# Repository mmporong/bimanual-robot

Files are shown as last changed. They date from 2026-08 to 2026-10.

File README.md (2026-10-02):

# HOLD THE FLOW · 이동형 양팔 물 서빙 로봇

웹에서 테이블의 물 주문을 받아 주방에서 물을 따르고, 컵을 상판에 싣고 이동해
테이블에 놓은 뒤 도크로 복귀하는 로봇이다. 동국대 DAPIER 피지컬 AI 부트캠프
MS Team의 공용 저장소이며, 이동·양팔 조작·관제를 하나의 주문으로 연결한다.

시뮬레이션의 전체 미션, 실차의 서비스 이동, 양팔 조작을 각각 시험했다.
실물에서 주문부터 물 서빙·충전까지 이어지는 전체 미션의 반복 검증은 남아 있다.

<p align="center">
  450×340 mm 프레임의 이동형 양팔 물 서빙 로봇 콘셉트
</p>

그림은 부품 배치를 설명하는 콘셉트다. 제작·충돌·관성 검토에는
[축척 모델](docs/assets/full_size_frame_20260910/model_overview.png)과 기구 사양을 사용한다.
실제 조립·센서 배치와 모델의 차이는 아래 하드웨어 항목에서 구분한다.

## 현재 구현과 검증 범위

| 영역 | 확인된 상태 | 남은 검증 |
|---|---|---|
| 웹 주문·관제 | 4테이블·냉수/온수 선택, 주문 큐, 배터리 분기, SQLite 복구, Action 결과 대기 | 물리 미션의 반복 주문·재시작 복구, 실제 배터리·충전 신호 연결 |
| Isaac 전체 미션 | 도크 출발·양팔 물붓기·상판 운반·재파지·테이블 배치·도크 복귀 1회 통과 | 현행 순정 왼손으로 전체 미션 재시험, 물체 인식 입력, 충전 물리 |
| 순정 왼손 접촉 | 10 g·등가 질량 210 g 강체 컵의 파지·상승·놓기·손 분리 시험 통과 | 컵 변형·물 유동·이동 중 운반·실물 파지 |
| JD-AMR 실차 이동 | 물 받는 곳·table_01/table_02 접근과 도크 복귀 기록 확보 | 팔 작업 완료 신호 연결, 현행 양팔 차체·하중의 통합 평가 |
| 실물 왼팔 IK | 상대 DLS IK·엔코더 피드백으로 컵 동반 상승을 관찰한 기록 | 현행 양팔 보정으로 계획 재생성, 책상 완전 분리·TCP 정밀도·운반·놓기 |
| SmolVLA 조작 | 정책 파트에서 40개 에피소드 학습 정책의 주방 조작 1회 완주 보고 | checkpoint·영상·보정·데이터 원본 연결, 공통 조건 반복 평가 |
| 물체·물 양 인식 | 컵 검출·평면 변환·IK 도구, 액면·흘림 판정 설계 | 실물 카메라 보정, 컵별 mL 보정표, 붓기 정지 연동 |
| 모델 | 58링크·57관절의 URDF/Xacro와 CAD, 정적 계약 검사 | 실측 장착 좌표·접촉·관성·구동 추종의 일치 |

시뮬 성공, 팀 보고, 실물 관측을 같은 성과로 합산하지 않는다. 전체 미션 시뮬은
구형 강체 패드와 정답 물체 좌표를 사용했고, 실차 이동에서는 팔 작업을 대기로 대체했다.
실물 IK의 컵 동반 상승도 전체 픽앤플레이스 완료를 뜻하지 않는다.
실험 조건·원본 위치·변경 이력은 [진행 로그](PROGRESS.md)에 기록한다.

<!-- AUTO:PROJECT-STATUS:START -->
## 단일 원본 자동 요약

> 아래 표는 기계 YAML에서 생성한다. 수정하려면 표가 아니라 연결된 원본 파일을 고친다.

| 항목 | 현행 값 |
|---|---|
| 기계 개정 | `2026-09-22_left_stock_so101_gripper_selected` |
| 상·하부 프레임 | 450×340 mm |
| 상판 높이 | 720 mm |
| 왼손 | SO-101 순정 회전식 죠, TPU·오버캡 없음 |
| 오른손 | `ggao50_SO101_Parallel_Gripper` |
| RGB-D | Orbbec_Astra_S, 상판 위 250 mm |
| 베이스 | differential_two_wheel_two_ball_caster, Feetech_STS3215_C018_12V |
| 모델 상태 | `simulation_model_ready_physical_measurements_pending` |

원본: [`hold_flow_mechanical_v0_3.yaml`](design/mechanical/hold_flow_mechanical_v0_3.yaml)
과거 후보: [`finray_80mm_lip3_selection.yaml`](design/gripper/finray_80mm_lip3_selection.yaml)
<!-- AUTO:PROJECT-STATUS:END -->

## 미션과 MVP 범위

```text
도크 대기 → 테이블 물 주문 → 주방 이동·정렬·정차
  → 왼팔 컵 파지 + 오른팔 물통 파지 → 물붓기·물 양 확인
  → 물통 반환 → 컵 상판 적재·손 분리 → 테이블 이동·정차
  → 컵 재파지·테이블 배치·손 분리 → 도크 복귀
```

컵은 양팔 사이 상판에 놓고 운반한다. 주행 중 팔로 컵을 들지 않으며,
파지·붓기·놓기 전에 베이스를 정지한다. 도크 도착과 실제 충전 시작은 별도로 판정한다.

초기 실물 통합 범위는 등록한 작업대·한 종류의 컵과 물통·상온의 물·한 테이블이다.
웹의 4테이블·냉수/온수 선택 기능이 모든 조합의 물리 검증 완료를 뜻하지 않는다.
온수 조작, 다중 로봇 배차, 사람과 함께 쓰는 매장 상시 운용, 범용 조립·음성 태스크는
MVP에서 제외한다. 태스크 결정 원본은 [회의 결정과 실행 범위](docs/20260907_물서빙로봇_회의결정과_실행범위.md)다.

## 하드웨어와 모델

- 프레임: 상·하부 450×340 mm, 프로파일 기둥 4개, 4분할 프린팅 상판.
  상판 높이 720 mm, 바퀴 포함 폭 540 mm가 제작 기준이다.
- 양팔: SO-101 두 대. 왼손은 순정 회전식 죠를 사용하며 TPU·오버캡을 붙이지 않는다.
  오른손은 ggao50 순정 평면 죠이며 홈·교체형 인서트를 사용하지 않는다.
- 실물 조작 관제: 상단 RGB 1대와 손목 RGB 2대. 설계의 Astra S RGB-D와 구분한다.
  카메라 연결 확인은 영상 좌표와 팔 좌표의 보정 완료가 아니다.
- 실차 주행: Raspberry Pi 4B 4GB, ESP32, Astra S와 YDLIDAR G4.
  URDF의 LDS-03·원본 바퀴 배치와 실차 구성의 차이는 통합 전에 맞춰야 한다.
- 질량·하중: URDF 명목 빈 질량은 7.379 kg. 추가 적재 5 kg의 수동 평지 주행은
  예비 시험이며 정격 적재량·실측 총질량·연속 운전 성능으로 사용하지 않는다.

캘리브레이션은 [양팔 JSON과 보정 상태](calibration/README.md)로 관리한다.
현행 양팔 follower와 오른쪽 leader는 팀원의 그리퍼 재조립 후 새 보정을 반영한다.
양팔 실행은 `calibration/bi_follower`·`bi_leader`를 사용하며 단일팔 과거 사본을 섞지 않는다.
이전 IK 관측은 교체 전 보정의 시험 기록이다. 이전 정책의 수집 보정과 호환은 별도
확인하며, 보정 변경 뒤 이전 raw 목표·IK mapping·계획 packet을 그대로 재사용하지 않는다.
영점·TCP·개구 대응과 실물 정밀도는 캘리브레이션 파일 저장 여부와 구분한다.

기구·CAD·모델 생성과 검증은 [450×340 모델 설명](docs/20260910_450x340_4분할상판_URDF_IsaacSim_모델.md),
[CAD 출력물](design/cad/README.md), [URDF 설명](src/hold_flow_description/README.md)을 따른다.

## 이동·관제·조작의 연결

```text
웹 주문 → 주문 큐·미션 상태기계 → ExecuteManipulationSkill ROS 2 Action
  → Unix socket JSON → Isaac phase executor → 물리 결과·진행 feedback
```

주문·미션·요청 ID와 phase, backend, checkpoint를 결과에 연결한다.
Action의 성공·실패·취소·timeout을 확인한 뒤 다음 phase로 진행하고,
취소된 주문의 늦은 결과가 상태를 다시 전진시키지 않도록 한다.
ROS 2 Jazzy의 Python 3.12와 Isaac Sim 5.1의 Python 3.11은 프로세스로 분리한다.
현재 Isaac 실행은 Articulation 제어와 로컬 IPC를 사용하며 ROS Bridge 관절 Topic 실행과 다르다.

### 웹 주문과 실행 모드

주문 ID 중복 방지, 우선순위 큐, 활성 미션 한 건, 재시도·실패 종료를 구현했다.
연속 주문의 도크 복귀 생략과 저배터리 충전 선행은 관제 로직으로 시험했다.
SQLite는 주문·큐·명령 이력을 보존하지만, DB 복구만으로 Isaac 물리 world까지 복원되지는 않는다.

| backend | 실행하는 범위 |
|---|---|
| `immediate` | CPU 관제 dry-run. 명령을 즉시 성공 처리 |
| `ros2-mock` | ROS 2 Action의 feedback·result·취소·timeout 계약 |
| `ros2-planned-artifact` | 저장된 시뮬 산출물의 해시·phase 증거 대조. 새 물리 실행 아님 |
| `ros2-planned-session` | 상태를 보존하는 executor 세션. 연결한 mock/물리 실행기의 provenance 확인 필요 |
| `ros2-planned-roundtrip` | 한 Isaac world의 도크 출발·조작·바퀴 주행·서빙·도크 복귀 |

왕복 물리 검증은 1번 테이블 냉수 한 건에 한정한다. 충전 접점·충전 물리,
반복 주문의 world reset, 다른 테이블·물통 조합은 별도 검증 대상이다.
HTTP 응답 성공과 주문의 물리 성공을 구분한다.
실행법은 [웹 관제](docs/20260922_웹주문_미션관제_dry-run.md)와
[Action·IPC·왕복 executor](docs/20260922_ExecuteManipulationSkill_ROS2_Action.md)에 있다.

### 실차 주행과 시뮬 주행

| 환경 | 지도·경로·추종 | 근거와 한계 |
|---|---|---|
| JD-AMR 실차 | Cartographer 지도 생성, 저장 지도 AMCL, NavFn·RPP, Collision Monitor, RGB-D 면 정렬·접근 | 물 받는 곳·테이블·도크 시험. 팔 동작·충전 시작 미포함 |
| Isaac 식당 | 알려진 배치의 점유격자·A*, lookahead 차동구동 추종·최종 pose 정렬 | 시뮬 좌표·정적 배치 조건. Nav2·실물 SLAM 실행 아님 |

실차 기록의 대표 예시는 table_02 왕복 186.5초, table_01 왕복 175.0초이며
각 실행의 Nav2 목표 10개가 완료됐다. 위치 오차는 AMCL·odom·센서 TF의 내부 추정이다.
같은 날 한 명령으로 table_02 → 도크 → table_01 → 도크를 연속 완료한 기록도 있다.
팔 작업은 각 5초 대기로 대체했고 충전 시작은 포함하지 않았다. 통제구역 시험에서는 RPP 예측 충돌 검사를 끄고
Collision Monitor를 유지했다. 사람 주변 운용 성능이나 전체 물 서빙 성공으로 확대하지 않는다.

실차 코드와 최신 이동 기록은 [JD-AMR 저장소](https://github.com/mmporong/jdamr_cube_ros)가 관리한다.
이 저장소의 [선행 이식 문서](docs/20260912_JDAMR_SLAM_실기체이식.md)는 준비 절차이며,
이후 이동 시험의 미완 상태를 판단하는 최신 근거로 사용하지 않는다.
지도만 저장하지 않고 station·footprint·TF·센서·도착 정렬을 함께 맞춰야 한다.

## 계획 기반 조작과 모방학습

계획 기반 조작은 FK로 파지점·병 입구의 위치와 자세를 계산하고 DLS IK로 관절 목표를 구한다.
컵은 몸통 중간에 수평 접근하며, 물붓기에서는 오른쪽 병 입구를 왼쪽 컵 위로 옮기고
입구 위치·기울기·붓는 방향·관절 연속성을 함께 제한한다. IK는 시연 학습이 필요하지 않다.

| 방식 | 현재 상태 | 비교할 내용 |
|---|---|---|
| 계획 기반 `PLANNED_ALL` | Isaac 접촉·붓기·운반 기준선, 실물 상대 IK 시험 | 좌표·보정 오차, 형상·마찰, 재설정 비용 |
| 모방학습 | SmolVLA 주방 실물 완주의 팀 보고. ACT 데이터 계약·인계 도구 | 같은 물체·시작 조건의 성공 횟수, 개입, 시간, 물 양 |
| `HYBRID` | phase별 backend 선택 계약 | 공통 평가 뒤 학습이 도움이 되는 phase만 교체 |

`ACT_ALL`은 저장소의 ACT 전략 계약명이다. SmolVLA를 자동으로 실행하는 adapter나
현행 통합 rollout이 완료됐다는 뜻은 아니다. SmolVLA·ACT 연결 시 모델별 관측·행동 키,
관절 순서·단위·보정·checkpoint를 맞춰야 한다. 학습 loss와 물리 과업 성공률도 구분한다.

HYBRID 구현 시 기존 backend 종료, 관절 속도 0·허용 자세 확인, 잔여 action chunk 폐기,
lease 해제 후 제어권 전환을 요구한다. 이 전환의 실물 통합 검증은 아직 남아 있다.
IK와 정책 명령을 동시에 쓰지 않으며, 어느 phase를 IL로 바꿀지는 동일 평가 조건에서 결정한다.
학습과 수집은 [양팔 IL·Hub·다른 PC 학습 인계](docs/20260911_양팔_IL_데이터수집_HuggingFace_학습_인계.md)를,
실물 IK 계획·mock과 제한 사항은 [픽앤플레이스 준비](docs/20260929_IK_픽앤플레이스_실행전_준비.md)를 따른다.

## 시뮬레이션과 실물 전환

Isaac Sim 5.1에서 URDF를 가져와 독립 강체 컵·병과 그리퍼의 접촉으로 파지한다.
물체를 손목에 강제로 붙이지 않으며, 물은 PhysX GPU PBD 입자로 모델링한다.
파지 유지·미끄럼·용기 자세·입자 분포·상판/테이블 지지·손 분리·도착을 검사한다.

전체 왕복 `dock_roundtrip02`는 한 실행에서 12개 phase와 물리 판정을 통과했다.
시뮬 시간은 473.892초, 최종 입자는 컵 687개·병 227개·외부 4개다.
운반 중 추가 입자 손실은 없었지만 전체 무유출·실측 mL 정확도를 뜻하지 않는다.
구형 80 mm 강체 패드·정답 좌표 조건이며 Nav2와 충전 물리는 실행하지 않았다.

현행 순정 왼손은 별도 강체 컵 접촉 시험을 통과했다. 이를 구형 패드의 전체 미션이나
실물 물붓기 결과로 대체하지 않는다. 실물 상대 IK는 잠정 손목 대응·엔코더 피드백으로
컵 동반 상승을 관찰한 단계이며, 절대 좌표 정밀도·안정 운반·놓기는 아직 검증 전이다.

실물 전환은 관절·TCP·카메라/작업셀 대응 → 건식 파지·놓기 → 계량 물붓기 →
상판 운반 → 이동·조작 통합 순서로 확인한다. Isaac 6.0은 목표 계약이며 5.1 실행 근거와 구분한다.
고정 베이스의 정적 프리뷰도 물리 접촉 시험과 다르다.

- [URDF 프리뷰·순정 죠 접촉 시험](docs/20260918_URDF_Isaac51_작업환경_프리뷰.md)
- [양팔 PBD 물붓기](docs/20260921_양팔_PBD_물붓기_시뮬레이션.md)
- [4테이블 식당·상판 운반·영상 생성](docs/20260921_식당_시뮬레이션_환경.md)

## 물 양 판정

시뮬레이션은 컵·병·외부 영역의 입자 수로 물 전달과 손실을 평가한다.
실물의 목표량 정지는 아직 연결 전이며 다음 흐름으로 개발한다.

```text
컵·액체·흘림 영역 분리 → 원근·기울기 보정 → 액면/충전율
  → 컵별 실측 mL 보정표 → UNDER / TARGET / OVER / SPILL / UNKNOWN
```

YOLO 검출 박스나 액면 높이 비율이 곧 부피는 아니다. 한 종류의 컵과 물부터
저울·눈금 계량값으로 대조한다. 목표량·허용오차·불확실 관측 처리와 감속·정지 연동을
정한 뒤 실제 붓기 시험으로 확인한다.

## 데이터·실패 기록·평가

에피소드·영상·가중치·rosbag은 Git 밖의 비공개 Hub 또는 외부 저장소에 보존한다.
[데이터 인덱스](data/README.md)에는 수집 조건·버전·해시·split·checkpoint 연결을 남긴다.
정책 파트의 팀 보고를 공용 인덱스·원본 평가 기록에 연결하는 작업은 남아 있다.

원본 시연은 한 번 보존하고 phase 시작·종료와 성공 기준을 표시해 전체·phase 학습에 재사용한다.
실물과 시뮬 데이터는 구분하고, 실패 원본을 성공 BC 데이터에 무조건 섞지 않는다.

```text
증상·실행 조건·근거 보존 → 원인 가설/기각 → 확인된 원인
  → 시스템 수정 또는 시연 보강 → 같은 조건 재시험 → 다른 조건 회귀 평가
```

하드웨어·연결, 좌표·보정, 로직, 데이터 분포, 측정 문제를 분리한다.
[failure bank](tools/failure_bank.py)는 근거 보존·해시 검증·집계를 담당하며,
[실패 규약](data/failures/README.md)에 가설·조치·재시험을 연결한다.

공통 평가에는 전체/phase별 성공 횟수와 전체 시도 수, 개입·재시도, cycle time,
실측 물 양·흘림, 위치·조명·초기 잔량 변화, 관측 지연을 기록한다.
한 실행의 12개 phase 통과를 12회 반복 성공으로 쓰지 않으며,
정책 loss·주행 도착·물체 파지·물 양 정확도를 각각 평가한다.

## 연산·무선 분담

| 위치 | 목표 책임 |
|---|---|
| GPU 노트북 | 정책 학습·추론, 고부하 비전, 웹 UI·기록 분석 |
| Raspberry Pi 4B | 센서·TF·Nav2·미션·정렬, 명령 중재·하드웨어 연결 |
| ESP32·서보 | 바퀴·관절 구동과 상태 전달 |

카메라·LiDAR·구동계는 로봇 안에서 유선 연결하고 Pi↔노트북을 로컬 네트워크로 연결한다.
모든 모델의 원격 추론·실행이 통합 검증된 상태는 아니다. 관측/명령 시각·유효기간,
중복·두절·재연결과 실제 정지 동작을 확인해야 한다.
Pi 5 전환은 후순위이며 주행·센서·통신 부하를 측정한 뒤 결정한다.
팀원의 GPU 서버도 모델·학습 조건을 별도 기록하며 장비 확보만으로 성능을 확정하지 않는다.

## 시작하기

개발 기준은 Ubuntu 24.04, ROS 2 Jazzy, C++17, Python 3.12, LeRobot 0.6.1이다.
시뮬 물리 실행에는 Isaac Sim 5.1의 별도 Python 환경을 사용한다.
구성 요소별 설치·빌드는 [ROS 패키지 설명](src/README.md)과 각 실행 문서를 따른다.

CPU 웹 관제만 확인할 때:

```bash
cd "$HOME/bimanual-robot"
python3 tools/service_order_server.py \
  --backend immediate --port 8765 \
  --state-dir "$HOME/.local/state/hold-flow/service"
```

`http://127.0.0.1:8765/`에서 주문·큐·phase·이력을 확인한다. 이 모드는 물리 실행이 아니다.
종료는 실행한 터미널에서 `Ctrl+C`를 사용한다. Isaac 연동에는
[Action 실행 문서](docs/20260922_ExecuteManipulationSkill_ROS2_Action.md)의 서버·socket·backend 설정이 추가로 필요하다.

문서·자동 요약과 모델을 검사할 때:

```bash
cd "$HOME/bimanual-robot"
python3 tools/ci/check_local_markdown_links.py
python3 tools/ci/sync_readme_status.py
python3 src/hold_flow_description/scripts/validate_description.py
```

## 다음 통합 작업

1. 현행 보정·그리퍼·카메라·작업셀과 정책 데이터/checkpoint의 대응을 고정한다.
2. 같은 조건에서 계획 기반/학습 조작의 건식 파지·놓기와 물붓기를 반복 평가한다.
3. 컵별 물 양 계량·판정·정지 연동, 상판 적재와 테이블 전달을 확인한다.
4. 실차의 작업 대기를 조작 Action 완료 신호로 바꾸고 주문별 전체 미션을 연결한다.
5. 반복 주문·실패·취소·재시작·무선 두절을 평가하고 도크 복귀와 충전 시작을 구분한다.

## 역할과 저장소 진입점

| 담당 | 범위 |
|---|---|
| 임주영 | SLAM·Nav2·station·도크 복귀, 미션 연결, URDF·Isaac Sim 검증 |
| 장준서 | 양팔 텔레옵·모방학습·정책 비교·실물 rollout |
| 지민석 | 컵·물통·액체 인식, 물 양·흘림 판정 |
| 공통 | 차체·그리퍼·전원·배선, 통합 시험 |

| 경로 | 용도 |
|---|---|
| [design](design/cad/README.md) | 기구 사양·CAD·출력물 |
| [src](src/README.md) | description·interfaces·mission 등 ROS 2 코드 경계 |
| [data](data/README.md) | 에피소드·평가·실패 계약과 외부 데이터 인덱스 |
| [docs](docs/20260904_양팔로봇_프로젝트_인계.md) | 설계·실행법·팀 인계 |
| [research](research/R33_산업용_피킹과_IL_ACT_적용경계.md) | 외부 연구의 적용 판단 |
| [PROGRESS.md](PROGRESS.md) | 날짜별 실험·실패 수정·검증 근거·변경 이력 |

## 저장소 운영

제품 상태는 README, 상세 실행 기록은 PROGRESS와 분야별 문서에 둔다.
변경은 작업 브랜치에서 검증하고 PR로 main에 반영한다. 위험도 라벨은 검토 안내이며,
Draft가 아닌 PR은 필수 검사 통과 후 자동 병합한다. CODEOWNERS·추가 승인 인원은 요구하지 않는다.
자동화 안내는 Actions 요약에 남기고 봇 댓글은 만들지 않는다. GitHub 기본 알림은 수신자 설정을 따른다.

실물 동작은 요청된 실행 범위에서 수행하고, 물체를 든 상태의 hold와 토크 해제를 구분한다.
동시 제어권·관절 한계·충돌·스톨·timeout·흘림의 처리도 실행 환경에서 확인한다.
파일 단위로 스테이징하며 데이터·모델·대용량 로그는 커밋하지 않는다.

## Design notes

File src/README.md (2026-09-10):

# src 구현 계약

이 디렉터리는 물 서빙 로봇의 실행 코드를 담는다. 현행 태스크·정책·구현 순서는
[2026-09-07 물 서빙 로봇 회의 결정](../docs/20260907_물서빙로봇_회의결정과_실행범위.md)을
따른다. 과거 붓기안의 MoveIt·로드셀 중심 구조는 현행 구현 기준이 아니다.

현재 실제 ROS 2 패키지는 `hold_flow_description`뿐이다. 아래 나머지 패키지는 책임과
인터페이스를 먼저 고정한 **구현 예정 경계**이며, 빈 패키지를 완료물처럼 만들지 않는다.

## 패키지별 언어와 책임

| 패키지 | 상태 | 주 언어·기술 | 현행 책임 | 착수 조건 |
|---|---|---|---|---|
| `hold_flow_interfaces` | 예정 | ROS IDL | 미션·정렬·policy·물 양·로그 계약 | policy 번호·상태명 확정 |
| `hold_flow_description` | v0.3 정적 검증 완료 | xacro·YAML·URDF | 300 mm·720 mm 모바일 베이스, 혼합 그리퍼 SO-101×2, Astra S·LDS-03 TF | 실측값 반영과 Isaac 동역학 검증 |
| `hold_flow_bringup` | 예정 | Python·YAML | 실물/sim launch profile, lifecycle 실행 순서 | 첫 실행 패키지와 함께 |
| `hold_flow_web` | 예정 | FastAPI·HTML·JavaScript·rclpy | 웹 요청 검증, `ServeDrink` Action client | 요청 JSON 계약 |
| `hold_flow_navigation` | 예정 | Nav2·SLAM Toolbox·AMCL·DWB·Collision Monitor | 지도, station registry, 장애물 회피, 도킹 staging | 실험 공간·station 실측 |
| `hold_flow_perception` | 예정 | Python·RGB-D·YOLO·OpenCV·tf2 | station 정렬, 컵·물통·선반·테이블·액면 인지 | 컵·카메라 POC |
| `hold_flow_motion` | 예정 | C++·Eigen·FollowJointTrajectory | PLANNED phase의 그립·IK·시작·복귀·검증 궤적·붓기 폐루프 | 새 팔 역할·선반 좌표 |
| `hold_flow_safety` | 예정 | C++·rclcpp·tf2 | command lease, 관절 delta, timeout, 정지 | 첫 실물 명령 전에 |
| `hold_flow_hardware` | 예정 | Python→C++ 선택·LeRobot·serial | 좌우 SO-101 포트 단독 소유, 상태·명령 변환 | 포트·서보 변종 감사 |
| `hold_flow_learning` | 예정 | Python·LeRobot 0.6.1·PyTorch·ACT | phase 표시 수집, ACT_ALL·로컬 ACT, rollout, 실패/HIL 데이터 | phase·backend 계약·데이터 게이트 |
| `hold_flow_mission` | 예정 | Python·rclpy | 웹→이동→조작→서빙→도킹 상태기계 | Action mock 통과 |
| `hold_flow_logging` | 예정 | Python·rosbag2·JSON·Parquet | request ID로 미션·episode·실패 연결 | 인터페이스와 함께 |
| `hold_flow_isaac` | importer·정적 계약 존재 | Python·USD·Isaac Sim 6.0·ROS 2 Bridge | v0.3 URDF→USD, Nav2·양팔·센서 SIL, sim/real gap | Isaac 장비에서 USD·접촉·gain 검증 |

## 명령과 데이터 경로

```text
웹 브라우저
  → hold_flow_web
  → ServeDrink Action
  → hold_flow_mission
      ├─ NavigateToPose / DockRobot → Nav2 → base controller
      ├─ AlignToStation → perception
      └─ ExecuteManipulationSkill → phase router
            ├─ backend=PLANNED → motion ┐
            └─ backend=ACT → learning   ├→ command_mux → safety_guard → 양팔 bridge
                                        ┘

Astra S RGB-D → perception → station pose / fill estimate → mission·phase router·logging
joint state·action·strategy·backend·safety event → logging → episode sidecar / failure bank
```

### 소유권 규칙

- 베이스 이동 중에는 Nav2만 베이스 명령 lease를 가진다.
- 팔 조작 중에는 베이스 lease를 해제하고 정지 상태를 확인한다.
- PLANNED·ACT·teleop 중 하나만 팔 명령 lease를 가진다.
- backend 전환은 관절 속도 0, 허용 자세, 남은 ACT chunk 폐기와 기존 lease 해제 뒤에만 한다.
- 좌우 SO-101 시리얼 포트는 `hold_flow_hardware` 한 프로세스만 연다.
- perception은 actuator 명령을 직접 내리지 않고 판정 결과만 반환한다.
- Action 취소는 mission→policy executor→hardware까지 전파한다.

## 먼저 만들 인터페이스

| 인터페이스 | 목적 | 성공 결과에 포함할 것 |
|---|---|---|
| `ServeDrink.action` | 전체 미션 실행 | request ID, final state, error code |
| `AlignToStation.action` | 주방·테이블 정밀 정렬 | pose, quality, timestamp |
| `ExecuteManipulationSkill.action` | PLANNED·ACT·HYBRID 조작 | skill/strategy, phase별 backend·checkpoint, failure stage/code, intervention count |
| `EstimateFillLevel.srv` 또는 Action | 물 양 판정 | estimated mL, class, confidence, cup calibration ID |
| `MissionEvent.msg` | 계층 간 공통 로그 | request ID, stage, event, timestamp |
| `SafetyState.msg` | 실행 허용·정지 상태 | active lease, stop reason, timestamp |

긴 작업에는 Action을 사용한다. 물 양을 한 프레임에서 즉시 읽으면 Service로 시작할 수
있지만, 연속 프레임을 모아 판정하고 취소·feedback이 필요하면 Action으로 올린다.

## 병렬 구현 순서

### policy lane — 팀 1순위

1. policy 1·2 내부 phase와 회의의 `3번 policy` 의미를 확정한다.
2. `PLANNED_ALL / ACT_ALL / HYBRID` preset과 phase별 시작·종료·backend 계약을 IDL로 고정한다.
3. PLANNED_ALL mock·dry-run으로 phase·성공 판정·안전 정지를 연결한다.
4. 주방·테이블 장면을 수동 배치해 phase 표시 LeRobot smoke episode를 수집한다.
5. ACT_ALL과 phase별 ACT 과적합 기준선을 만든다.
6. 같은 scenario matrix에서 세 전략을 비교한다.
7. rollout 실패를 strategy·backend·phase별로 수집하고 확인된 원인만 수정·보강한다.

### 이동·IK lane — 사용자 담당

1. `stations.yaml`에 충전소·주방·테이블 계약을 만든다.
2. SLAM 지도 작성과 AMCL/Nav2 반복 이동을 분리한다.
3. DWB를 첫 controller로 두고 실측 footprint·속도·가감속 한계를 적용한다.
4. LDS-03 obstacle layer와 Collision Monitor 감속·정지 영역을 검증한다.
5. 장애물 회피·재계획 실패 코드와 Nav2 feedback을 기록한다.
6. 새 팔 역할과 선반 frame을 기준으로 IK 시작·복귀 자세를 검증한다.
7. 현행 v0.3 URDF를 Isaac Sim에서 USD로 만들고 같은 인터페이스·접촉·gain을 검증한다.

### 인지 lane

1. Astra S에서 컵·액면 가시성 POC를 한다.
2. YOLO segmentation 라벨과 컵별 보정표를 만든다.
3. `UNDER/TARGET/OVER/SPILL/UNKNOWN` 판정과 confidence를 반환한다.
4. 가림이 실제 주요 실패 원인일 때만 손목 카메라를 검토한다.

### 통합 lane

1. 실제 Nav2·policy 대신 mock Action server로 상태기계를 먼저 통과시킨다.
2. phase router와 세 preset을 mock PLANNED·ACT backend로 검증한다.
3. 각 실제 패키지를 하나씩 mock과 교체한다.
4. backend 전환, Action 결과·취소·timeout·재시도를 검증한다.
5. 마지막에 웹 요청부터 충전 시작까지 request ID 하나로 연결한다.

## 코드 리뷰에서 반드시 확인할 것

- 현재 태스크가 물 서빙 하나인지, 과거 커넥터·음성·범용 태스크가 재진입하지 않았는가
- 단위가 degree/radian, mm/m 중 무엇인지 필드와 코드에서 명시됐는가
- `frame_id`와 timestamp가 있으며 오래된 TF·영상이 거부되는가
- timeout·취소·실제 hold/stop 경로가 있는가
- 베이스와 팔, PLANNED와 ACT의 명령 소유자가 동시에 활성화되지 않는가
- strategy·phase·backend·checkpoint 또는 planner/trajectory/controller 버전이 기록되는가
- 카메라·joint state·action의 실제 fps와 주기 지터를 기록하는가
- policy ID, checkpoint, dataset, calibration, code commit을 연결했는가
- 성공률뿐 아니라 단계별 실패 코드와 사람 개입을 남기는가
- 실물·Isaac Sim·혼합 데이터의 dataset ID와 split이 분리됐는가
- TODO·stub·빈 패키지를 구현 완료로 보고하지 않았는가

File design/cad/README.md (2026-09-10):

# HOLD THE FLOW v0.3 CAD

이 디렉터리는 300×300 mm 상판과 720 mm 작업 높이 이동형 양팔 베이스의 파라메트릭 CAD 원본과 생성물을 담는다. 시스템 외곽·배치·판 두께·팔 어댑터·기둥·카메라 마스트·라이다 받침 치수의 단일 원본은 `../mechanical/hold_flow_mechanical_v0_3.yaml`이다. 장공·경량 포켓·구동 캐리어처럼 제작 방식에 속하는 세부 치수는 생성기 안에 있으며 실측 게이트에서 확정한다.

## 생성 범위

- 300 mm 하판·중판·8 mm 상판
- 상판 지지용 20×20×644 mm 중공 기둥 4개
- SO-101 교체형 어댑터 2개
- 후방 중앙 20×20×240 mm 카메라 마스트와 Astra S 거치대
- LDS-03을 z=165 mm에 두는 80 mm 받침대
- JD-AMR 휠·C018용 측면 캐리어
- 앞·뒤 볼캐스터 공용 어댑터와 1/2/3 mm shim

SO-101 팔과 그리퍼 원본은 이 생성기가 다시 그리지 않는다. ROS 모델은 `../../src/hold_flow_description`의 SO-101 메시, 왼쪽 기본 moving jaw, 오른쪽 ggao50 치수 프록시를 쓴다.

## 재생성

```bash
cd "$HOME/bimanual-robot"
"$HOME/.local/bin/uv" venv --python 3.11 "$HOME/.cache/bimanual-cad-venv"
"$HOME/.local/bin/uv" pip install \
  --python "$HOME/.cache/bimanual-cad-venv/bin/python" cadquery pyyaml
"$HOME/.cache/bimanual-cad-venv/bin/python" design/cad/generate_hold_flow_cad.py
```

결과는 `exports/step`, `exports/stl`, `exports/manifest.json`에 생긴다. URDF가 참조하는 CAD STL은 `../../src/hold_flow_description/meshes/cad`에도 같은 바이트로 복사된다. STEP 헤더 생성 시각을 정규화하므로 같은 입력의 재생성 diff가 흔들리지 않는다.

## 2026-09-08 생성 결과

- 모든 BREP 유효
- 상판: 약 300.017×300.017×8.017 mm STL 경계
- 상판 지지기둥: 20.002×20.002×644.002 mm, 4개
- 부품별 명목 재료 밀도를 적용한 구조 질량 합: 2,866.2 g
- 300 mm 판 3종과 644 mm 기둥은 K1 Max 수납 불가 또는 안전 여유 없음
- FDM 후보 중 어댑터·카메라 부품·라이다 받침대·구동 캐리어·캐스터 부품은 K1 Max 안전 경계 안

상판은 K1 Max 300 mm 명목 폭과 같고 CAD 허용오차까지 더해지므로 한 장 출력 부품으로 취급하지 않는다. 8 mm 절삭 판재가 기준이다. 하판·중판은 통합 벽 때문에 현행 형상을 한 장 출력할 수 없으므로 분할 설계 또는 절삭 판재+별도 브래킷으로 바꾸기 전에는 제작 준비 완료가 아니다.

`estimated_total_material_mass_g`는 중공 CAD 형상에 명목 밀도를 곱한 값이다. FDM infill, 실제 판재, 실제 2020 압출재의 질량을 대신하지 않는다.

## 컵 오버캡

왼쪽 기본 SO-101 죠용 오버캡은 별도 생성한다.

```bash
cd "$HOME/bimanual-robot"
"$HOME/.cache/bimanual-cad-venv/bin/python" \
  design/gripper/generate_so101_cup_overcaps.py \
  --cup-diameter 70 --radial-clearance 0.8
python3 "$HOME/.codex/skills/3d/scripts/analyze_stl.py" \
  design/gripper/exports/cup_overcaps/stl/so101_cup_overcap.stl
```

현재 70 mm 기본형은 BREP 유효, 약 24.5×44.0×30.0 mm, 고체 PETG 22.0 g/개다. 분석기는 스트랩 슬롯 때문에 서포트 필요로 판정했고 `Y-90`을 제안했지만 회전은 적용하지 않았다. 실물 죠와 컵을 재기 전에는 fit coupon 단계다.

## M1 공차 쿠폰과 기존 슬라이서

기존 M1 쿠폰과 250 mm 설계용 PETG 슬라이서 도구는 이력으로 남아 있다. v0.3 전체 구조를 그대로 슬라이싱하는 용도가 아니다.

```bash
cd "$HOME/bimanual-robot"
"$HOME/.cache/bimanual-cad-venv/bin/python" design/cad/generate_m1_coupons.py
```

실제 출력 전에는 프린터·노즐·재료를 확정하고 각 STL을 다시 분석한다. 한 번에 `--all`로 기존 구조를 슬라이싱하지 않는다.

## 실측 게이트

1. 상판·하판·중판 재료, 판 두께, 평탄도와 제작 방식
2. 2020 압출재 단면·선형 질량·브래킷·체결 위치
3. SO-101 베이스 체결공 중심거리와 M 규격
4. C018 혼, JD-AMR 휠 허브, 외부 베어링 축 공차
5. 앞·뒤 볼캐스터 플랜지, 접촉 높이, preload
6. Astra S 하단 체결과 실제 광학 중심
7. LDS-03 하부 체결공과 레이저 스캔면 높이
8. 컵 외경·테이퍼와 기본 죠·오버캡 스트랩 간섭

실측 후 YAML과 생성기 상수를 함께 고치고 STEP/STL·URDF·Isaac 검증을 다시 수행한다.

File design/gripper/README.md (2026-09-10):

# 좌우 그리퍼 출력 부품

현행 v0.3은 왼팔에 기본 SO-101 회전식 죠, 오른팔에 ggao50 `SO101-Parallel-Gripper`를 쓴다. 왼쪽은 컵 오버캡 fit coupon, 오른쪽은 평행 죠용 교체 인서트를 따로 관리한다.

## 왼쪽 기본 죠용 컵 오버캡

컵 그리퍼를 최종 선정하기 전, 기본 SO-101 죠에 같은 오버캡 두 개를 각각 스트랩으로 묶는 P0 설계다. 두 죠를 하나의 강체로 연결하지 않는다.

```bash
cd "$HOME/bimanual-robot"
"$HOME/.cache/bimanual-cad-venv/bin/python" \
  design/gripper/generate_so101_cup_overcaps.py \
  --cup-diameter 70 --radial-clearance 0.8
python3 "$HOME/.codex/skills/3d/scripts/analyze_stl.py" \
  design/gripper/exports/cup_overcaps/stl/so101_cup_overcap.stl
```

- 기본 컵 외경 70 mm, 허용 파라미터 60~82 mm
- 약 24.5×44.0×30.0 mm, 고체 PETG 명목 22.0 g/개
- 동일 부품 2개, 오목 접촉면과 3 mm 하단 턱
- 현재 3D 분석 결과: 원본 자세도 스트랩 슬롯 서포트 필요
- 분석기가 제안한 `Y-90` 회전은 적용하지 않음
- 상태: 실물 죠·컵 맞춤과 젖은 컵 미끄럼 시험 전 fit coupon

산출물은 `exports/cup_overcaps` 아래 STEP·STL·manifest에 있다.

## 오른쪽 ggao50 파지 인서트

ggao50 죠에 볼트로 붙이는 교체형 파지면이다. 죠 본체는 그대로 두고 물체에 닿는 면만 갈아 끼운다.

## 왜 필요한가

ggao50 죠의 파지면은 완전 평면이다. STL을 직접 측정한 결과 축정렬 평면이 전체 면적의 69%이고 곡면이나 홈이 없다. 평면 죠와 원통은 선접촉 두 줄이라 병이 죠 안에서 자기 축으로 돌고, 기울일 때 축 방향으로 미끄러진다. 붓기에서는 주둥이 방향이 매번 달라진다는 뜻이다.

## 죠 실측 기준값

`STL/Parallel Jaw Gripper - leftgripper.stl` 직접 측정.

| 항목 | 값 |
|---|---|
| 파지 평면 | `x = -49.4` |
| 손가락 방향 범위 | `Y -84.2 ~ -11.5` (72.5 mm) |
| 병 축 방향 범위 | `Z -29.3 ~ 28.2` (뿌리 기준 57.5 mm) |
| 파지면 면적 | 2,449 mm² |
| 최대 개폐 | 105 mm |

## 파지면은 테이퍼다

죠 파지면을 평면으로 잘라 재 보면 손끝으로 갈수록 좁아지는 **하나의 테이퍼**다. 끊긴 두 면이 아니다.

```
높이 = 0.682 × Y + 67.5      (R² 0.958)
  손끝 Y = -84  ->   8.7 mm
  뿌리 Y = -16  ->  57.5 mm
```

**인서트는 뿌리 쪽에만 붙인다.** 손끝은 접촉 높이가 8.7 mm라 병을 세워 잡는 데 기여가 없고 기울일 때 회전축이 된다. 높이 40 mm 이상인 구간이 `Y ≥ -40.4`이므로, 부착 창을 `Y -42 ~ -14`의 28 mm로 잡고 외곽을 죠 테이퍼에 맞춘 사다리꼴로 만든다.

| | 값 |
|---|---|
| 부착 창 | `Y -42 ~ -14` (28 mm) |
| 외곽 | 사다리꼴, 높이 34.0 → 52.3 mm |
| 죠 외곽에서 인셋 | 2 mm |
| 볼트 | M3 2개, 손가락 방향 중심거리 20 mm, `Z = 0` |

볼트를 손가락 방향으로 두는 이유는 홈이 병 축(`Z`) 방향으로 파여서 `Z = 0` 중심선에는 항상 재료가 남기 때문이다.

## V홈 폭은 부착 창이 제한한다

부착 창이 28 mm라 홈 폭도 그 안에서 정해진다.

| 홈 폭 | 면으로 받는 최대 지름 | 인서트 두께 | 유효 개폐 |
|---:|---:|---:|---:|
| 24 mm (기본) | **D62.7** | 11.0 mm | 83.1 mm |
| 26 mm | D67.9 | — | — |
| 28 mm | D73.2 | — | 창 여유 없음 |

기본값 `24 mm`는 `source_container` 규격(`200~330 mL`, 지름 `50~62 mm`)을 면으로 받는다. 그보다 큰 병은 홈 모서리에 걸려 2점 접촉이 된다.

쐐기 마찰 증폭은 `135°`에서 1.08배로 거의 없다. **V홈의 가치는 마찰이 아니라 지름과 무관한 자기중심에 있다.** 미끄러짐은 TPU 패드가 맡는다 — 마찰계수를 0.2에서 0.8~1.0으로 올리므로 효과가 4~5배로 훨씬 크다.

## 세 형상

| 인서트 | 두께 | TPU | 시간 | 용도 |
|---|---:|---:|---:|---|
| `insert_A_flat_pad` | 7.0 mm | 8.4 cm³ | 47m | 평면. 마찰만 올림 |
| `insert_B_v_groove` | 11.0 mm | 11.4 cm³ | 1h 02m | V홈. 자기중심 추가 |
| `insert_C_trapezoid` | 8.1 mm | 8.2 cm³ | 47m | 사다리꼴 홈. 원통·평면 겸용 |

전부 같은 부착 규격이라 볼트를 풀고 바꿔 끼우면 된다.

## 부착

- M3 볼트 2개, 손가락 방향 중심거리 20 mm
- 인서트에 `Ø3.4` 관통, 파지면 쪽에 `Ø6.5 × 1.6` 자리파기로 머리를 묻는다
- 죠 쪽 `Ø3.4` 관통 2개는 [`drill_jaw_insert_holes.py`](drill_jaw_insert_holes.py)가 상류 STEP 에 직접 뚫는다. `prepare_ggao50_print.py` 가 자동으로 호출하므로 따로 실행할 필요는 없다
- 볼트는 `M3 × 30 mm`. 인서트 두께 11 + 죠 13.5~15 + 와셔 + 락너트를 지난다
- 죠 뒷면이 테이퍼라 너트 자리를 파지 않는다. **평와셔로 받는다**

### 죠 구멍 실측 근거

| 항목 | 값 |
|---|---|
| 파지면 평면 | `x = -49.4` |
| 블레이드 두께 `Y=-38` | 13.51 mm (`x -62.91 ~ -49.40`) |
| 블레이드 두께 `Y=-18` | 15.00 mm (`x -64.40 ~ -49.40`) |
| 구멍 | `Ø3.4`, `Y = -38 / -18`, `Z = 0`, X 방향 관통 |

`Z = 0` 중심선을 쓰는 이유는 홈이 병 축(`Z`)으로 파여도 중심선에는 항상 재료가 남기 때문이다. 구멍을 뚫은 뒤 두 죠 모두 watertight 이고 부피는 21.36 / 21.32 cm³ 다.

## ggao50 본체 출력

상류 STL 은 라이선스 표기가 없어 이 저장소에 두지 않는다. 필요할 때 받아서 방향을 잡고 슬라이싱한다.

```bash
cd "$HOME/bimanual-robot"
python3 design/gripper/prepare_ggao50_print.py --out "$HOME/gcode/ggao50"
```

받은 STL 과 생성한 G-code 는 `--out` 아래에만 생기고 커밋 대상이 아니다.

| 부품 | 방향 | 서포트 | PETG | 시간 |
|---|---|---|---:|---:|
| `backplate` | Y+90 | tree | 67.1 cm³ | 2h 49m |
| `leftgripper` | 원본 | tree | 26.4 cm³ | 1h 23m |
| `rightgripper` | X180 | tree | 26.4 cm³ | 1h 23m |
| `cameraplate` | 원본 | tree | 21.2 cm³ | 1h 42m |
| `connectorplate` | 원본 | tree | 12.0 cm³ | 41m |
| `pinion` | **X+90** | **off** | 2.7 cm³ | 17m |

한 팔 `155.8 cm³` ≈ `198 g`, `8h 14m`. 양팔이면 `396 g`, `16h 29m`이다.

`pinion` 은 X+90 으로 눕히면 서포트가 사라진다. 나머지 다섯은 회전으로 없앨 수 없어 tree 서포트를 베드에서만 세운다(`--plate-only`). 죠는 파지면이 수직이 되는 원본 방향을 유지해 접촉면에 서포트 자국이 남지 않게 한다.

## 인서트 출력

인서트는 TPU 95A 로 뽑는다.

```bash
python3 design/cad/slice_k1max_petg.py --out "$HOME/gcode/inserts" \
  --tpu --infill 100% --support off design/gripper/exports/stl/insert_*.stl
```

| 인서트 | TPU | 시간 |
|---|---:|---:|
| `insert_A_flat_pad` | 8.4 cm³ | 47m |
| `insert_B_v_groove` | 11.4 cm³ | 1h 02m |
| `insert_C_trapezoid` | 8.2 cm³ | 47m |

양팔이면 각 4개, 세 형상 전부 뽑아도 합계 `112 cm³`, `9h 44m`이다.

노즐 `230 °C`, 베드 `45 °C`. TPU 는 인필 100% 로 뽑아야 V 형상이 눌리지 않는다.

## 재생성

```bash
cd "$HOME/bimanual-robot"
"$HOME/.cache/bimanual-cad-venv/bin/python" design/gripper/generate_jaw_inserts.py
"$HOME/.cache/bimanual-cad-venv/bin/python" design/gripper/generate_jaw_inserts.py --v-angle 120 --groove-width 30
```

출력은 `exports/step`, `exports/stl`, `exports/manifest_inserts.json`이다.

## 선정 방법

계산으로 고르지 않는다. 세 형상을 TPU 95A로 뽑아 같은 병으로 기울임 시험을 한다.

1. 병을 물리고 `112.3°`까지 천천히 기울인다
2. 축 방향으로 흘러내리는지 확인한다
3. 주둥이 방향이 도는지 확인한다

그리퍼 조립 전에 죠 2개만 손으로 눌러도 재현된다.

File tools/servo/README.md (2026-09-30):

# STS3215 서보 도구

그리퍼 캘리브레이션과 서보 상태 점검에 쓰는 최소 도구다. 절차와 실측값은
[`docs/20260909_그리퍼_캘리브레이션_인계.md`](../../docs/20260909_그리퍼_캘리브레이션_인계.md)에 있다.

## 처음 받는 사람 — 환경 준비

**1) 저장소를 받는다.**

```bash
git clone git@github.com:mmporong/bimanual-robot.git
cd bimanual-robot
```

**2) pyserial 을 확인한다.** 외부 의존성은 이것 하나뿐이다.

```bash
python3 -c "import serial; print(serial.__version__)"
```

없으면 설치한다. Ubuntu 는 apt 쪽이 낫다.

```bash
sudo apt install python3-serial
```

**3) 시리얼 포트 권한을 확인한다.**

```bash
id -nG | tr ' ' '\n' | grep dialout
```

안 나오면 그룹에 넣고 **로그아웃 후 다시 로그인**한다. 재로그인 전에는 적용되지 않는다.

```bash
sudo usermod -aG dialout $USER
```

**4) 보드를 연결한다.** 12V 어댑터를 먼저 꽂고 USB 를 연결한다.

```bash
ls -l /dev/serial/by-id/
```

`usb-1a86_USB_Single_Serial_...-if00` 이 보이면 준비가 끝났다.

**5) 읽어본다.** 여기까지 오면 설치가 맞은 것이다.

```bash
cd ~/bimanual-robot/tools/servo
python3 servo_read.py
```

## 실행

도구가 같은 디렉터리의 `sts_bus.py`를 읽도록 서보 도구 디렉터리에서 실행한다.

```bash
cd ~/bimanual-robot/tools/servo
python3 servo_read.py
```

포트는 `--port` 를 생략하면 `/dev/serial/by-id` 에서 자동으로 찾는다. 보드가 두 개
이상이면 어느 것인지 알려주므로 그때만 지정하면 된다.

## 도구

| 파일 | 하는 일 | 서보가 움직이나 | `--execute` |
|---|---|---|---|
| `servo_read.py` | 위치·한계·오프셋·게인·부하·온도 읽기 | 아니오 | 불필요 |
| `servo_release.py` | 구동 해제 | 아니오 | 불필요 |
| `servo_offset.py` | 지금 자세가 지정 값으로 읽히게 눈금 이동 | 아니오 | 필요 |
| `servo_limits.py` | 각도 한계 변경 | 아니오 | 필요 |
| `servo_goto.py` | 지정 위치로 이동 (델타·부하·정지·발산 감시) | **예** | 필요 |
| `execute_safe_recovery.py` | 2도 충돌 감사 경로를 내부 속도 제한으로 동기 복귀 | **예** | 필요 |
| `servo_home.py` | 지금 자세를 2047 로 — 범위가 0/4095 를 안 넘게 | 아니오 | 필요 |
| `servo_record_ranges.py` | 손으로 훑는 동안 범위 기록, `--capture-only`로 후보 JSON 저장 | 아니오 | 후보 기록에는 불필요 |
| `servo_apply_ranges.py` | 백업·Phase 대조 후 한계값만 적용, 실패 시 복구 시도 | 아니오 | 적용 시 필요 |
| `small_raw_jog.py` | 현재 위치 기준 손목 +32 tick 왕복 또는 보정 대조 후 ID 6 부분 개폐 | **예** | 이동 시 필요 |
| `servo_check_calibration.py` | lerobot JSON 과 서보 EEPROM 대조, 범위 오염 검사 | 아니오 | 불필요 |
| `servo_check_phase.py` | STS3215 Phase(주소 18)를 기대값과 대조 | 아니오 | 불필요 |
| `export_lerobot_calibration.py` | 서보 EEPROM 값을 lerobot JSON 으로 내보내기 | 아니오 | 필요 |
| `sts_bus.py` | 통신 헬퍼(체크섬 검증 포함). 직접 실행하지 않는다 | — | — |
| `lerobot_gripper_protection.patch` | lerobot 로컬 패치 — 연결 때 그리퍼 토크를 낮추는 코드를 끈다 | — | `git apply` |

전체 흐름(전원 → 텔레옵 → 녹화 → 학습)은
[`docs/20260910_텔레옵_IL_사용법.md`](../../docs/20260910_텔레옵_IL_사용법.md) 에 있다.

`--execute` 가 없으면 전부 dry-run 으로 끝난다. 무엇을 바꿀지 먼저 출력해서 보여준다.

### 기존 오프셋을 유지하는 범위 갱신

`servo_record_ranges.py --capture-only`로 양팔 후보를 별도 파일에 기록한다.
이 단계는 EEPROM이나 원본 JSON을 바꾸지 않는다. 오른손 ggao50 후보에는
`--gripper-drive-mode 1 --gripper-margin 40`을 사용한다. wrist_roll은 0~4095로
두며, 나머지 관절은 사용자가 기구 간섭이 없는 범위를 수동으로 기록한다.

`servo_apply_ranges.py`에는 명시한 포트, `--candidate` 후보 JSON,
`--expected` 기록 전 EEPROM 백업 JSON과 `--phases` ID 1~6 기대값을 전달한다.
기본 실행은 읽기 대조만 한다. `--execute --report-dir <새 로컬 결과 폴더>`를
추가하면 토크 OFF·현재 위치·백업 일치를 확인하고 MIN/MAX만 쓴다.
offset·Phase·게인·보호 설정·이동 목표는 쓰지 않는다. `drive_mode`는 JSON의
정규화 방향이며 Phase와 다른 설정이다.

적용 전 상태와 결과는 결과 폴더의 `journal.jsonl`에 저장한다. ACK 유실,
readback 불일치, 중단 요청이나 결과 저장 실패 시 변경을 시도한 한계값을
복구하고 전체 대조를 수행한다. 통신이 끊기면 복구도 실패할 수 있으므로
`rollback_verified`와 `rollback_errors`를 확인한다. 이 도구는 팔별로 적용하며
한쪽 성공이 다른 팔의 성공을 뜻하지 않는다.

적용 결과 `applied_pending_power_cycle`은 동작 검증 완료가 아니다. 팔을 받친
상태에서 12V를 껐다 켜고 읽기 대조를 다시 수행한 뒤 개폐 방향·끝점 여유를
확인한다. 새 범위/오프셋을 반영한 JSON으로 IK 계획과 raw 목표를 다시 만들며,
과거 계획이나 학습 정책이 같은 동작을 낸다고 가정하지 않는다. 리더 보정과
LeRobot 캐시는 자동 갱신하지 않는다. 사용할 양팔 follower 설정은
[`calibration/README.md`](../../calibration/README.md)를 기준으로 선택한다.

기존 `servo_record_ranges.py --execute`에는 부분 실패 자동 복구가 없으므로
새 범위의 기체 적용에는 위 분리된 도구를 사용한다.

### 전원 재인가 후 작은 그리퍼 개폐 시험

`small_raw_jog.py`에 `--calibration <양팔 중 해당 팔 JSON>`과
`--expected-gripper-phase 12`(현재 왼손) 또는 `76`(현재 오른손)을 지정하면
ID 6만 시험한다. 기본은 읽기 대조이며 `--output <새 로컬 JSON>`이 필요하다.
사용자의 실물 실행 요청 범위에서 `--execute`를 추가한다.

양팔 중 해당 팔의 6축 보정·토크 OFF와 ID 6 Phase·위치 모드를 대조한 뒤,
`drive_mode`에 따른 열림 방향으로 128 tick 이동하고 시작점 기준 64 tick 위치로
부분 되닫기한다. 닫힘 끝점으로 되돌아가지 않는다. 위치 판정 허용 오차는 16 tick이며
이 시험 결과를 전체 개폐나 파지 정밀도로 해석하지 않는다.

실패 시 자동 복귀하지 않는다. 현재 위치 목표·속도/가속도 복원 후 OFF를 마지막으로
전송하고 최대 3회 읽어 확인한다. `release_attempts`와 `stop_errors`를 보존하며,
오류나 최종 OFF 미확인은 종료 코드 2다. 온도·부하·EEPROM 접근은 없다.
`partial_cycle_reached`는 서보 위치 단계의 완료이고, 죠 동작을 관측하지 않았다면
`physical_jaw_motion_verified`는 false로 남긴다.

## 리허설

실물에 붙이기 전에 모의 버스로 끝까지 돌려 본다. `py_compile` 은 리허설이 아니다.

```bash
cd ~/bimanual-robot/tools/servo
python3 servo_goto.py --mock --goal 3000 --execute
python3 servo_goto.py --mock --mock-wall 3300 --goal 3000 --execute   # 걸림 경로
python3 servo_offset.py --mock --mock-sign -1 --target 3600 --execute # 부호 반대인 서보
python3 servo_limits.py --mock --min 760 --max 3600 --execute
python3 execute_safe_recovery.py --plan /tmp/holdflow_left_recovery_plan.json --mock --execute
```

## 그리퍼 캘리브레이션 한 판 (실제 순서)

죠를 다시 물린 뒤 이 다섯 줄이면 끝난다. 절차의 근거는
[인계 문서 3절](../../docs/20260909_그리퍼_캘리브레이션_인계.md)에 있다.

```bash
cd ~/bimanual-robot/tools/servo

# 1. 죠를 손으로 완전히 맞닿게 한 뒤
python3 servo_read.py --id 6                          # 구동이 0 인지 확인
python3 servo_offset.py --target 3600 --execute       # 그 자세를 3600 으로

# 2. 죠를 손으로 완전히 벌린 뒤
python3 servo_read.py --id 6                          # 열림 끝 값을 읽는다 (예: 506)
python3 servo_limits.py --min 546 --max 3480 --execute

# 3. 12 V 를 껐다 켠다 — EEPROM 을 쓴 뒤 재부팅 없이 움직이면 제어가 꼬인다

# 4. 검증 — 20 mm 를 명령하고 자로 잰다 (3500 − 20 × 30.5 ≈ 2890)
python3 servo_goto.py --goal 2890 --execute
```

`--execute` 를 빼고 먼저 돌리면 무엇을 바꿀지 보여주고 끝난다.

## 문제 해결

| 증상 | 먼저 볼 것 |
|---|---|
| `시리얼 포트가 없습니다` | USB 케이블이 충전 전용은 아닌지. `lsusb` 에 `1a86` 이 뜨는지 |
| 포트는 있는데 `응답한 서보가 없습니다` | **12V 어댑터**. USB 만으로는 서보가 안 산다. 그다음 보드→첫 서보 3핀 선 |
| 특정 ID 하나만 무응답 | 데이지체인에서 그 단의 커넥터. **전원을 끄고** 다시 꽂는다 |
| `Permission denied` | `dialout` 그룹. 추가했으면 재로그인했는지 |
| `0.5s 동안 정지 (목표까지 N 남음)` | 하드 스톱이거나 걸림. 구동을 풀고 손으로 그 방향으로 되는지 본다 |
| `부하 N > 600` | 진짜 걸림. 피니언 허브와 레일의 서포트·브림 잔재를 본다 |
| `적용 실패 — 값이 바뀌지 않았습니다` | EEPROM 잠금. 구동이 걸려 있으면 안 써진다. `servo_release.py` 먼저 |
| `예상한 100 만큼 안 움직였습니다` | 오프셋 레지스터가 다른 계열일 수 있다. 자동으로 원복됐으니 그대로 두고 문의 |
| `목표가 각도 한계 밖입니다` | `servo_read.py` 로 한계를 보고, 의도한 것이면 `servo_limits.py` 로 먼저 넓힌다 |

## 되돌리기

`servo_offset.py` 와 `servo_limits.py` 는 바꾸기 전 값을
`~/.cache/bimanual-robot/servo_backup.jsonl` 에 한 줄씩 append 한다. 덮어쓰지 않으므로
이력이 남는다.

```bash
cat ~/.cache/bimanual-robot/servo_backup.jsonl
```

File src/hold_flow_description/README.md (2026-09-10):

# hold_flow_description

300×300 mm 상판, 720 mm 작업 높이, SO-101 두 대, 왼쪽 기본 회전식 죠, 오른쪽 ggao50 평행 그리퍼 프록시, Astra S, LDS-03, 2륜+2볼캐스터를 하나의 TF 트리로 묶는 ROS 2 Jazzy 설명 패키지다.

## 좌표 기준

- `base_footprint`: 차체 중심의 바닥
- `base_link`: `base_footprint`에서 z=32.9 mm인 구동륜 축 높이
- 상판: 300×300×8 mm, 윗면 z=720 mm
- 좌우 팔 베이스: `(0, ±75, 726) mm`
- Astra S depth optical 중심: `(-110, 0, 970) mm`, 상판보다 250 mm 위
- LDS-03 후보 중심: `(100, 0, 165) mm`
- 구동륜 중심: `(0, ±160, 32.9) mm`, 기하 중심거리 320 mm
- 볼캐스터 중심: `(±120, 0, 12.5) mm`

바퀴 320 mm는 CAD 기하 중심거리다. Nav2 오도메트리에는 완성 차체의 직진·제자리 회전으로 보정한 유효 `wheel_separation`을 넣는다.

## 형상과 라이선스

`third_party/so_arm_101`과 `meshes/so101`은 TheRobotStudio SO-ARM100/101의 Apache-2.0 형상이다. 관절 원점과 한계는 로컬 JD-AMR에서 사용한 SO-101 설명을 유지한다. 왼쪽 moving jaw도 같은 범위로 포함했다.

오른쪽은 [ggao50 SO101-Parallel-Gripper](https://github.com/ggao50/SO101-Parallel-Gripper) 기준이다. 2026-09-08 확인 당시 라이선스 표기가 없어 원본 메시를 벤더링하지 않고, 공개 STL에서 측정한 치수로 만든 프로젝트 프록시를 `urdf/ggao50_gripper.xacro`에 둔다. 스트로크·작업공간·충돌 포락선 검토용이며 제조 원본과 같은 접촉면을 보장하지 않는다.

왼쪽 컵 오버캡은 아직 기본 URDF에 붙이지 않는다. 실물 죠와 컵을 재기 전 fit coupon 단계이기 때문이다. 생성기는 `design/gripper/generate_so101_cup_overcaps.py`다.

## 빌드와 검증

```bash
cd "$HOME/bimanual-robot"
source /opt/ros/jazzy/setup.bash
colcon build --packages-select hold_flow_description --symlink-install
python3 src/hold_flow_description/scripts/validate_description.py
python3 src/hold_flow_description/scripts/audit_urdf_quality.py --strict
python3 src/hold_flow_description/scripts/validate_isaac_contract.py
python3 src/hold_flow_description/scripts/import_isaac_sim.py --check-only
```

검사는 Xacro 확장, `check_urdf`, 커밋 URDF 일치, 메시 존재·CAD 복사본 해시, 양의 질량·관성, 관절축·hard/soft limit·dynamics, 16개 핵심 좌표, 바퀴·캐스터·기둥 수, 오른쪽 mimic 관절과 커스텀 구조의 primitive collision을 확인한다.

2026-09-08 결과는 46링크, 45관절, 축 관절 15개, 품질 문제 0건이다. 이 결과는 정적 모델 일관성 증거이며 Isaac Sim 물리 안정성이나 실물 안전 증거가 아니다.

## Isaac Sim 6.0

일반 Python에서는 정적 검사만 실행한다. Isaac Sim 설치 장비에서는 Isaac의 `python.sh`로 USD를 만든다.

```bash
cd "$HOME/bimanual-robot"
/path/to/isaac-sim/python.sh \
  src/hold_flow_description/scripts/import_isaac_sim.py \
  --usd-dir "$HOME/bimanual-robot/build/isaac/hold_flow"
```

가져오기 옵션과 사후 접촉·gain 검증표는 `config/isaac_sim_6.yaml`에 있다. 커스텀 판·기둥·받침대는 CAD visual + 볼록 primitive collision을 쓰고, SO-101은 원본 메시 collision을 유지한다.

## 아직 측정해야 하는 값

- 상판 재질·실제 질량·평탄도와 2020 압출재 제품
- SO-101 베이스 체결공
- C018 혼–휠–외부 베어링 축 조합
- 앞·뒤 볼캐스터 플랜지·preload·접촉 높이
- Astra S 장착점·intrinsic·extrinsic
- 왼쪽 컵 오버캡 맞춤과 젖은 컵 마찰
- 오른쪽 ggao50 손목 변환과 정확한 충돌 메시
- 물 서빙 작업 자세별 팔↔팔·팔↔상판·팔↔카메라 충돌

전체 배치·가져오기·검증 경계는 `docs/20260908_300mm_720mm_양팔_URDF_IsaacSim_모델.md`에 있다.

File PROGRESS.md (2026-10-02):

# PROGRESS — 진행 로그

> 매 세션마다 최상단에 append. 세션 재개 시 여기부터 읽어 맥락을 이어받는다.

---

## 2026-10-02 | PR #54 새 양팔 캘리브레이션 통합과 충돌 해결

- 사용자 요청으로 `JANGJUNSEO`의 PR #54에 최신 main을 병합했다. 양팔 follower와 오른쪽 leader JSON은 팀원 커밋 `c75a93d2a173bd9bfff73e739b5b7a6df5f057a4`의 파일 전체를 채택했다. 그리퍼뿐 아니라 다른 축의 offset·범위도 바뀌므로 항목별로 이전 보정과 섞지 않았다. 왼팔 leader·단일팔 과거 사본은 유지했다.
- 충돌 5파일 중 JSON 3개는 새 팀원 보정, PROGRESS는 양쪽 이력 보존, 텔레옵 문서는 최신 실행 원본 링크와 새 보정 안내를 채택했다. 단일팔 과거 JSON을 양팔 파일에 복사하는 명령과 이미 해소된 FinRay 재보정 대기 설명은 제거했다. 새 보정 상태와 IK 이전 산출물 무효화를 대표 README의 관련 기능에 반영했다.
- 이전 main의 활성 JSON 3개를 교체 전에 `$HOME/.local/state/bimanual-robot/calibration-pr54-20261002.5K71fR/calibration/`에 보존했다. 캘리브레이션 README에 출처·해시·ID 6 범위와 유효한 실행 폴더를 기록했다. 기존 mapping·snapshot·계획의 SHA 검사를 완화하지 않았으며, 새 JSON으로 재생성해야 한다. URDF 기하는 근거 없이 수정하지 않았다.
- 팀원이 보고한 오른쪽 ID 6 보호값 복원은 EEPROM 작업 기록이며 저장소 JSON 변경과 구분했다. 이번 작업에서는 실물·카메라·서보·캐시·IL 정책을 실행하거나 수정하지 않았고, 팀원의 새 보정과 현재 기체 EEPROM 일치를 재측정하지 않았다. Windows Enter 수정과 그 revert는 상쇄되며 녹화 도구의 현행 main 구현을 유지한다.
- 검증: 신규 JSON 3개는 팀원 원본과 바이트 일치·스키마·ID 고유성·범위 검사 PASS. 관련 회귀 138 PASS, 전체 로컬 회귀 816 PASS / 2 SKIP(194.34초), Python·YAML 구문·Markdown 101파일 링크·README 자동 요약·URDF/Xacro 계약 PASS. main 대비 제품 코드·워크플로·기구 변경은 없다. 팀원 실험 문서의 공백 오류를 제거하고 공개할 필요가 없는 SSH 계정·공인 주소를 예시 표기로 바꿨다. 별도 verifier가 관련 검증 65 PASS와 출처·해시·문서·기능 보존을 대조해 최종 PASS, 병합 blocker 없음으로 판정했다.

## 2026-10-02 | 완료 브랜치 정리와 대표 README 통합 최신화

- 사용자 요청으로 로컬 브랜치 7개·원격 브랜치 3개를 정리했다. squash 병합은 PR·파일 내용·patch 대응으로 대조했고, 오래된 통합 스냅샷은 후속 기능 보존을 확인했다. 삭제 전 전체 이력과 refs를 Git 밖의 bundle에 보존하고 verify를 통과했다. 별도 verifier의 PASS 뒤 예상 SHA를 재확인해 원격은 atomic·exact lease 삭제했다. 열린 팀원 PR #54와 JANGJUNSEO, 미푸시 노션 문서 브랜치 2커밋, 연결된 AMMR·PR 정책 작업 폴더는 보존했다. 복구 기록은 `$HOME/.local/state/bimanual-robot/branch-cleanup-20261002.VloVZc/cleanup.md`다.
- 대표 README의 날짜별 장문·구형 실험·중복 명령을 걷어내고 현재 미션·하드웨어·관제 backend·실차/시뮬 주행·계획/학습 조작·평가·실행 진입점으로 재구성했다. 공식 보정·실물 상대 IK 상태는 관련 기능에 반영하고 상세 원본은 기존 PROGRESS·분야 문서로 연결했다. 기구 YAML 자동 요약은 유지했으며 기구·캘리브레이션·제품 코드는 변경하지 않았다.
- 사용자 제공 `$HOME/Downloads/양팔로봇_노션_기획보고서_20261001.md`와 현재 코드·원본 결과를 대조했다. Cartographer/AMCL/NavFn/RPP 실차와 Isaac A*/lookahead를 구분하고, SmolVLA 완주 팀 보고와 공용 checkpoint·평가 연결 미완을 분리했다. 구형 패드 전체 왕복, 순정 죠 단독 접촉, 실물 영상상 컵 상승을 서로의 성공 근거로 대체하지 않았다.
- 시뮬 근거는 `/data/$USER/robot-artifacts/restaurant/dock_roundtrip02/result.json`의 473.892초·최종 컵687/병227/외부4·운반 추가 손실0·Nav2/충전 물리 미실행이다. 실차는 `$HOME/jdamr_data/portfolio_20261001/metrics.json`의 table_02 186.5초와 table_01 175.0초·각 Nav2 목표10개 완료를 확인했다. 주행 인계 `$HOME/jdamr_rgbd_ws/src/jdamr_cube_ros/jdamr_cube_navigation/evaluation/20261001_PORTFOLIO_HANDOFF_FOR_CODEX.md`에는 이후 연속 table_02→도크→table_01→도크 실행도 기록돼 있다. README 수치는 대표 두 실행으로 한정하며 전체 성공률·외부 계측 정확도·실물 물 서빙 성과로 쓰지 않는다.
- 로컬 링크 95개 문서·README 자동 요약·diff·CLI 옵션·관련 문서 회귀 5개가 통과했다. 독립 검토의 보완 두 건을 반영해 최신 연속 실차 이동을 추가하고 HYBRID 제어권 전환을 구현 완료가 아닌 요구사항으로 명시했다. 이 작업에서 새 로봇·카메라·시뮬 실행, 물리 실험, 봇 댓글·외부 알림은 수행하지 않았다.

## 2026-09-30 | PR #58 병합 전 CI 테스트 의존성 수정

- 작업 브랜치를 푸시한 뒤 PR #58의 전체 CI에서 805 PASS / 1 FAIL / 12 SKIP를 확인했다. 실패는 `test_execute_uses_exclusive_buses_and_composes_dashboard_monitor`의 `monkeypatch.setattr("serial.Serial", ...)`가 CI에 없는 pyserial을 가져온 것이었다. 실물 IK 동작의 실패가 아니다.
- 해당 테스트에서 실제 Serial 호출을 실패시키는 모의 모듈을 `sys.modules`에 주입했다. 검증된 포트 개방 우회를 막는 검사 목적은 유지하고, 테스트를 건너뛰거나 실제 통신 의존성을 추가하지 않았다. 제품 코드·워크플로·캘리브레이션·기체 상태는 변경하지 않았다.
- pyserial import 자체를 차단한 환경에서 실패했던 테스트 1개 PASS, 해당 파일 전체 63 PASS, pyflakes·diff 검사와 URDF/Xacro 계약 검사 PASS를 확인했다. 원격 전체 검사와 병합 결과는 PR #58의 최종 상태를 기준으로 확인한다. 사용자의 실물 정지 요청은 유지한다.

## 2026-09-30 | 왼팔 상대 IK와 엔코더 보정, 영상상 컵 동반 상승

- 사용자 요청에 따라 실물 왼팔 컵 접근을 이어갔다. 추가 캘리브레이션·실측·A/B 판독을 요구하지 않았다. 오른팔·리더·베이스는 움직이지 않았고 게인·EEPROM·보호·캘리브레이션·URDF는 변경하지 않았다. 온도·부하를 읽지 않았다.
- 공식 보정의 범위 중점은 LeRobot 각도 영점이며 URDF 영점 대응 인증은 아니다. 관측한 수평 죠에 맞는 손목 roll +90° 후보를 `tools/bench_relative_ik.py`에 분리했다. 첫 4축 오프셋은 0, 손목 후보는 0/90°만 허용하며 calibration/URDF 해시·관측 근거를 결합한다. 시작 FK·IK·raw 역변환·실물 범위 교집합·양자화 후 FK·충돌 표본은 같은 변환을 쓴다. 잠정 매핑·실물 정밀도·파지 인증 플래그는 false로 유지한다. 도구 CLI는 오프라인 계획만 작성한다.
- 작은 waypoint마다 P16의 목표 미도달로 멈추던 실행기를 보강했다. 기본 복귀 성공은 토크 유지, 실패/중단은 현재 위치로 진행 목표를 취소하며 토크 OFF를 보내지 않는다. 새 `execute_encoder_feedback()`는 이미 켜진 팔의 엔코더를 따라 명목 목표와 보정 명령을 구분한다. 전달당 최대 5 tick, 실제 위치 구간 ±10 tick, 10초 제한과 정체 중단을 유지한다. 실패 진단에 actual/target/command/bias와 표본을 남기고 속도·가속도를 복원한다. 기존 보정 goal의 연속 호출 보존과 최종 재판독으로 stale 성공을 막는다.
- 25 mm 명목 수평 추가 접근 `advance25b`는 실제 목표 ±3 tick 이내에 도달했다. 닫기는 그리퍼 2969→2484에서 추종 차이로 멈췄으며 접촉과 deadband를 구분하지 못했다. 이후 목표 2465/실제 2482의 제한된 추가 닫기를 유지했다. 모터 닫힘값을 파지 성공으로 사용하지 않는다.
- 기본 보정/추종 40/45 tick에서 10 mm·8 mm 명목 상승은 shoulder_lift에 각각 +22/+19 tick 오차가 남아 중단됐다. 나머지 축은 ±3 tick 이내였으나 잠정 FK의 실제 TCP 높이도 시작보다 내려갔다. 성공한 3 mm 후보는 어깨가 반대 방향으로 움직인 다른 자세 해이므로 단순히 높이만 줄여 해결한 것으로 해석하지 않는다. P16·중력·마찰의 정확한 물리 원인은 확정하지 않았다.
- 기본값 40/45는 그대로 두고 이 책상 시험에만 보정/추종 50/60 tick을 명시했다. 같은 이전 상승 끝점의 `lift06`은 target `[1933,2680,2174,1053,2079]`, actual `[1933,2682,2176,1055,2077]`로 도달했다. 이어진 15 mm 명목 상승 `lift07`도 target `[1933,2607,2224,1076,2079]`, actual `[1933,2609,2226,1077,2076]`로 도달했다. 마지막 6축 raw는 `[1933,2609,2226,1077,2076,2482]`, 유지 goal은 `[1933,2563,2224,1078,2078,2465]`, 토크는 모두 ON이다. raw 목표를 사후 수정하지 않았다.
- 상단 영상에서 컵 입구와 죠가 함께 위로 이동하고 손목 영상에서 컵 몸체는 비슷한 위치를 유지한 채 배경이 내려갔다. 별도 vision 검토도 **영상상 컵 동반 상승 확인 / 책상 완전 분리 미확인**으로 판정했다. 15 mm는 모델 상대 목표이지 실측 높이가 아니다. 파지력·안정 운반·놓기·전체 심투리얼 성공을 주장하지 않는다.
- 실행기는 최종 관절 목표를 축별 제한 명령으로 따라가므로 오프라인 비례 waypoint 경로와 동일하지 않다. 표본 자가충돌·명령 범위 모서리 검사도 연속 경로·컵·책상·오른팔 충돌 보증이 아니다. 실패 goal=current 동결 뒤 어깨 3 tick 처짐도 관측했으며, 토크 유지와 정확한 자세 유지를 구분한다. `ik_pick_place.run_sequence()`의 기존 토크 OFF 종료 경로는 이번 시험에서 사용하지 않았다.
- 로컬 근거는 `/data/$USER/robot-artifacts/restaurant/relative_ik_20260930.1eNfG9/`의 mapping·plan/result·전후 JPEG에 보존한다. 데이터·사진·실행 로그는 커밋하지 않는다. 대시보드 `http://127.0.0.1:8770/`는 PID 4193263으로 유지하며 별도 이동 프로세스는 종료됐다. 대시보드 종료는 해당 PID의 명령을 확인한 뒤 `kill -TERM 4193263`으로 수행하며 팔 토크 해제와는 별개다. 긴급정지 버튼은 토크 OFF다.
- 검증: 관련 7개 테스트 파일 196 PASS, pyflakes·diff 검사 PASS. 독립 verifier는 피드백 16개와 해당 파일 52개 PASS·미해결 HIGH 없음으로 판정했다. 별도 매핑 리뷰의 플래그 우회·빈 충돌 표본 문제와 fixture 회귀 누락을 수정했다. 이 검토 범위와 실물 영상 관측을 구분하며 전체 실물 실행기를 승인한 것으로 표현하지 않는다.

## 2026-09-30 | 공식 왼팔 보정 기록 완료와 활성 파일 동기화

- 사용자 중간 자세 확인 후 공식 half-turn homing을 기록하고, 손목 롤을 제외한 5축 범위를 수동 기록했다. 사용자 완료 응답에 따라 기록을 종료했다. 보드 offset·범위와 후보의 일치, 기존 Phase·P/D/I·모드·잠금 상태 유지, 6축 토크 OFF를 확인했다. 이동 목표는 보내지 않았으며 온도·부하는 읽지 않았다.
- `standard_calibration_20260930_left01/candidate.json`·`result.json`·`after_snapshot.json`을 로컬 실험 경로에 보존했다. 검증된 후보와 `calibration/bi_follower/arms_left.json`을 동기화했다. 이전 파일은 같은 폴더의 `active_calibration.backup.json`, 실제 보드 백업은 `before.json`이다. 오른팔·리더·IL 정책·데이터·LeRobot 캐시는 변경하지 않았다.
- 기존 보정 오류를 확정하지 않은 상태에서 재보정을 시작한 점을 사용자에게 설명했다. 동일 물리 각도에서 homing 차이를 고려한 새 어깨 정규화 각도는 이전보다 12° 낮다. 범위 기록 차이의 증거이지 전체 실물/모델 오차 원인의 확정은 아니다. 종료 raw는 `[2040,799,3064,2908,2044,2028]`, 토크 전축 OFF다. 명목 어깨각 -109.54°는 URDF 하한 밖이므로 종료 자세에서 컵 접근을 승인하지 않는다. 추가 수동 재보정을 요청하지 않았다.
- 활성 보정 SHA는 `69b3a38747f7f143670f795808beaeedaeffb6114a5b9b076e6cc330701e7fbe`다. 공식 후보와 JSON 값은 같으며 마지막 개행 차이로 후보·snapshot 해시는 `9a9328bec2bc350e69d75989bdb0c8c8231c875bf02cb15faafcf86477713873`이다. 이전 packet/raw 목표 재사용과 이전 IL 정책의 무검증 실행을 금한다. 캘리브레이션 저장 완료와 IK 위치 정밀도·실물 파지 완료를 구분한다.
- 신규 보정 도구·IK 테스트 합계 66 PASS / 3 FAIL이다. 실패 3건은 합성 수동 영점이 들어간 `ALIGN_MIDDLE` 경로의 양자화 후 FK 검사이며, 새 범위에서 발생했다. 기준을 낮추거나 기존 실측값으로 되돌려 감추지 않았다. 표준 규약 경로와 실물 보정 저장 대조의 통과를 전체 IK 준비 완료로 표현하지 않는다. 이 모의 경로 회귀는 미해결로 남긴다.

## 2026-09-30 | 추가 치수 측정 철회와 공식 SO101 수동 보정 시작

- 사용자가 반복된 자세·높이 측정 대신 정상적인 절차를 요구했다. JL 형태 확인은 관절 각도의 정밀 검증이 아니며, 팔꿈치·손목 높이 두 개만으로 영점을 확정한다는 이전 안내를 철회했다. 임의 수동 영점이나 책상 높이 이동으로 오차를 감추지 않는다.
- `tools/servo/standard_so101_calibration.py`는 설치된 LeRobot `SOFollower.calibrate()`를 호출한다. 일반 `robot.connect/configure`의 게인·가속도·보호 설정 쓰기를 피하고 버스 연결만 사용한다. 공식 절차의 중간 자세 입력과 전체 가동 범위 기록을 유지하며, 기존 보드 보정·활성 JSON을 별도 경로에 백업한다. 예외·사용자 취소 시 이전 보정을 복원·재판독한다. 온도·부하 판독과 이동 목표·토크 ON 명령은 포함하지 않는다.
- 왼팔만 연결해 공식 중간 자세 입력에서 대기 중이다. 백업 경로는 `/data/lim/robot-artifacts/restaurant/standard_calibration_20260930_left01/`이며 이 시점에는 새 homing offset을 기록하지 않았다. 새 후보가 완료돼도 활성 JSON은 자동 교체하지 않는다. 기존 정책의 보정과 새 IK 후보를 혼용하지 않으며, 보정 완료와 실물 IK 정확도·컵 파지 성공은 별도 판정이다.
- 현재 8770 대시보드는 실행 중이 아니고 오른팔 by-id 장치는 보이지 않는다. 다른 프로젝트 8090 프로세스에는 관여하지 않았다. 이번 단계는 토크 OFF의 왼팔 수동 보정이며 양팔 자동 실행이 아니다.
- 검증: 성공·예외·취소·잘못된 범위·초기 토크 ON·백업 충돌의 모의시험 6개 PASS, pyflakes·diff 검사 PASS. 독립 verifier 호출은 런타임 thread limit으로 실패해 별도 로컬 검토를 수행했다. 실제 새 보정과 컵 접근은 아직 완료되지 않았다.

## 2026-09-29 | 표준 관절 규약 실행 경로 복구와 현재 실물 재확인

- 사용자가 A/B 비교에서 B(손끝 아래로 접힘)를 현재 리셋 모습으로 확인했고, 필요시 재보정을 포함한 수정을 요청했다. 새 위치 판독은 왼팔 raw `[2010,769,2517,2826,982,1415]`, 토크 6축 OFF이며 저장 calibration SHA와 EEPROM homing offset이 일치했다. 목표값 `[1990,781,2511,2776,982,1415]`, 속도값은 모두 0이었다. 온도·부하 판독, 토크·위치·P·EEPROM 쓰기는 하지 않았다.
- 이전 실행 조건은 `joint_reference_v1`에서 정밀도 false만 허용하면서 실제 실행은 true만 요구해 정상 입력으로 도달할 수 없었다. 명목 규약 선택과 실측 정밀도 보증을 분리했다. `prepare --joint-convention lerobot_degrees_so101_new_calib`가 config/packet 해시에 결합되고, 실제 실행은 이 규약과 수동 영점 미사용을 요구한다. 규약 미지정·수동 영점 병용·충돌 실패는 포트 개방 전에 거부한다. 실측 작업셀·시작 위치·보정 대조·정지 감시·스톨 정지·단계 관측은 유지한다. 결과의 `physical_mapping_precision_verified`는 false다.
- 공식 new-calib URDF와 현재 팔 5관절 origin/axis/limit 및 6링크 visual/collision origin·mesh 파일명이 일치했다. IK FK와 렌더 FK의 팔 링크 위치 차이는 시험 자세 6개에서 최대 약 `2.3e-16 m`였으며, 서로 다른 FK 구현이 원인은 아니었다. 이는 실물 정밀도 측정이 아니다. 범위 중점 대신 임의 raw 2048이나 기존 수동 영점을 채택하지 않는다.
- 같은 B 저장 관절값의 오프라인 탐색에서 팔꿈치·손목 굽힘을 함께 -5/-10/-15/-20/-25도로 바꿨을 때 자가충돌 쌍은 5/1/0/0/0이었다(그리퍼 0.4 rad 가정). 이는 다섯 끝점 검사이며 실물 경로 승인이나 연속 충돌 검증이 아니다. 현재 실물은 움직이지 않았다.
- 상단·손목 카메라 3개가 온라인이다. 상단 영상은 왼팔 아래쪽이 잘리고 손목 영상은 책상 아래를 향해 접힘 부위 대조에 부족하다. 팔을 들고 기다리게 하지 않고 상단 카메라만 옆으로 옮겨 베이스부터 손끝까지 보여 달라고 요청했다. 컵 파지·리셋 이탈의 실물 완료로 보고하지 않는다.
- 검증: 관련 5개 테스트 파일 95개 PASS(54.64초), pyflakes·diff 검사 PASS. 표준 규약의 실제 packet 검증·실행 진입 경로를 테스트에서 우회하지 않도록 바꿨으며 버스·감사는 모의했다. 기존 검토 에이전트 호출은 런타임 thread limit으로 실패해 별도 로컬 검증 패스를 수행했다. 독립 승인으로 표시하지 않는다. 캘리브레이션·URDF·모터 설정은 변경하지 않았다.

## 2026-09-29 | 잘못 채택한 수동 영점의 사용 철회와 각도 규약 비교

- 사용자가 리셋 자세의 15 cm 높이 설명이 실물과 맞지 않는다고 지적했다. 해당 수치는 검증되지 않은 수동 raw→URDF 영점으로 계산한 값이지 실측 높이가 아니다. 이를 근거로 사용자에게 높이 재측정을 요구한 판단을 철회한다. 기존 수동 기준과 그 기준으로 만든 접근 후보를 검증된 실물 매핑으로 사용하지 않는다.
- 같은 저장 리셋 raw에서 수동 기준과 로컬 LeRobot `MotorNormMode.DEGREES` 해석을 대조했다. 손목 굽힘은 -2.813° 대 86.374°, 손목 roll은 -0.088° 대 -93.670°다. 기준 변경이 각각 -89.187°/+93.582°의 차이를 만들었다. 수동 기준은 모델에서 손을 앞으로 뻗게 하고, 범위 정규화 기준은 아래로 접히게 한다. 후자도 모델 간섭이 남아 있으므로 정답으로 자동 채택하지 않는다.
- 공식 상류 `TheRobotStudio/SO-ARM100`의 pinned commit `eecbe3e0a9ebb23e25ad7b2759b03884c6660903`, `Simulation/SO101/so101_new_calib.urdf`를 열어 대조했다. SHA-256 `3a65d2d35e68a8d2f0c2cc176d19b884506543c93ba72980145b80abe276022c`가 NOTICE와 일치하며, 현행 왼팔 5관절의 origin/axis/limit 속성도 일치한다. 이 검사는 모델 출처 일치이며 현재 실물의 서보 영점 검증은 아니다. 캘리브레이션 JSON·URDF 관절 형상·EEPROM·IL/텔레옵 설정은 변경하지 않았다.
- `compare_joint_conventions.py`는 저장 snapshot을 두 방식으로 계산하고 어느 해석도 실물 매핑으로 인증하지 않는 JSON과 A/B 그림을 만든다. 로컬 결과는 `restaurant/calibration_20260929.BVaxly/reset_convention_comparison01.json`·`.png`다. 사용자에게 A/B 중 실물에 가까운 접힘 모습만 확인 요청했으며 팔을 들거나 움직이거나 새 캘리브레이션을 하라고 요청하지 않았다.
- 독립 리뷰에서 실물 execute가 미검증 reference를 통과시키고, reference를 빼면 midpoint로 돌아가는 문제를 발견했다. 첫 포트 개방 전 검증된 매핑을 요구하도록 수정했다. 현행 v1은 검증 상태를 표현하지 못하므로 실물 execute는 현재 사용할 수 없으며, 이를 README·실행 준비 문서에 명시했다. 오프라인 prepare/check/mock/snapshot은 유지한다. 단순히 검증 필드를 true로 바꿔 통과시키는 방법은 제공하지 않는다.
- 누락/미검증 기준의 포트 미접근과 미검증 기준의 offline mock 완료를 포함한 관련 77개 검사, pyflakes·diff 검사가 통과했다. 이번 작업은 잘못된 실물 해석의 원인을 드러내고 실행으로 이어지지 않도록 수정한 것이며, 실물 좌표 보정이나 컵 파지 완료가 아니다.
- 별도 code-reviewer 재검토에서 기존 HIGH 해소·신규 이슈 0건을 확인했다. 관련 소비 경로 86개 검사와 pyflakes·diff 검사가 통과했다. 리뷰 역할이 요구한 LSP 진단 도구가 없어 형식 판정은 APPROVE가 아닌 COMMENT이며, 이를 독립 승인이나 실물 실행 준비 완료로 표시하지 않는다.

## 2026-09-29 | 비접촉 확인과 사용자 리셋 후 시작 상태 재획득

- 사용자는 그리퍼/손목이 책상에서 떠 있으며 리셋 자세로 바꿨다고 확인했다. 이전 자세의 약 12 mm 명목 책상면 관통을 실물 접촉으로 해석하지 않는다. 이전 시작 snapshot에 결합된 세 경로 검토는 현재 실행 근거로 재사용하지 않는다.
- 새 읽기 전용 `restaurant/calibration_20260929.BVaxly/left_user_reset_reference01.json`과 상단 영상 `top_user_reset01.jpg`를 확보했다. 왼팔 6축 토크 OFF이며, 정렬 기준 각도는 약 `[0.527, -104.000, 87.824, -2.813, -0.088]`도다. 어깨가 URDF 하한보다 약 4° 밖으로 계산되지만 이를 근거로 URDF 한계나 저장 영점을 임의 변경하지 않았다. 새 자세의 명목 자가충돌은 없고, 닫힌 그리퍼·손목의 최저점은 가정 책상면보다 약 147 mm 높다. 실측 높이가 아니므로 실물과 대조가 필요하다.
- 새 snapshot에서 컵 뒤 상부·컵 상부 후보를 다시 계산해 `bench_cup_user_reset_candidates01.json`에 저장했다. 두 끝점은 가동 범위와 모델 끝점 검사를 통과하지만 초기 회복·연결 경로는 미검증이다. 리셋 어깨를 더 음의 방향으로 접는 이전 상승 후보는 사용하지 않는다. 실물 이동·설정 쓰기·온도/부하 판독은 하지 않았다.

## 2026-09-29 | 사용자 정렬 기준 등록과 실제 범위를 반영한 상부 접근 검토

- 사용자가 q=0 참고 자세에 맞췄다고 확인한 순간의 읽기 전용 snapshot을 `restaurant/calibration_20260929.BVaxly/left_user_aligned_reference01.json`에 묶었다. 이후 사용자가 팔을 내려놓아 새 snapshot `left_referenced_current01.json`을 별도로 읽었다. 두 자세를 혼동하지 않으며 기준 재현을 위해 팔을 들고 기다리게 하지 않는다. 관측한 왼팔 6축 토크는 OFF였고 이번 작업에서 움직임·게인·EEPROM 쓰기는 없었다. 기준은 수동 정렬이며 정밀도 검증은 아니다.
- 새 기준으로 기존 IK를 실행하면 손목 roll 약 -87° 해가 raw 가동 범위를 벗어났다. 사후 clipping이나 각도 감기로 덮지 않고 IK 탐색과 감사에 URDF·실물 raw 한계의 교집합을 적용했다. 컵 뒤 상부와 컵 상부는 roll 약 +92.8°의 같은 분기로 계산됐고 양자화 뒤 모델 FK 위치 오차는 각각 0.3342/0.4622 mm다. 실물 TCP 정확도가 아니다. 결과는 `bench_cup_referenced_candidates01.json`에 보존했다.
- `review_bench_pregrasp_path.py`는 현재→초기 상승→두 상부 끝점을 최대 10 tick 간격으로 검사한다. 포트 없이 입력 해시·관절 한계·왼팔 비인접 메시 자가충돌·가정 책상면·컵 지름 80 mm/높이 100 mm에 5 mm 여유를 더한 보수적 AABB를 검사한다. raw↔개구 대응이 미보정이므로 0/0.5/1/1.74533 rad 네 가정을 구분한다. 세 경로 후보를 비교했으며 어느 것도 실물 실행 승인으로 표시하지 않았다.
- 어깨만 -30°인 후보는 네 개구에서 초기 구간 포함 34표본의 컵 여유영역 겹침이 있었다. 어깨 -30°·팔꿈치 +15° 후보는 손목 재정렬 구간에도 일부 개구의 겹침이 남았다. 어깨 -45°·팔꿈치 +15° 후보는 213표본·관절 한계 여유 최소 13.538°·자가충돌 0이며, 초기 상승 이후 두 상부 끝점 연결 160표본은 네 개구 모두 컵 AABB 겹침 0이었다. 시작 명목 책상면 관통 11.692 mm와 초기 컵 여유영역 겹침은 보존했다. 시작보다 더 하강하지 않고 책상면을 벗어난 뒤 재진입하지 않았지만, 전체 sampled clear는 여전히 false다. AABB 겹침은 실제 컵 접촉으로 단정하지 않는다.
- 세 결과는 로컬 `bench_cup_pregrasp_path_{shoulder_only,retract_and_lift,retract_and_raise_high}_review01.json`에 저장했다. 작성 중 임시 `bench_cup_pregrasp_path_review01.json`만 제거했고 최종 세 결과로 검토 이력을 보존했다. 실제 책상면 대응·현재 책상 접촉·오른팔 배치·개구 보정·연속 경로 검증은 남아 있다. 사용자에게 현재 손목/그리퍼가 책상에 닿는지만 물었으며 팔을 들거나 옮기라고 요청하지 않았다.
- 관절 기준·IK·제한 실행 회귀 123개와 새 경로 검토 9개가 통과했다. pyflakes·구문·diff 검사도 통과했다. 새 도구는 별도 작성자와 메인 검토 패스를 분리해 메시 누락·관절 한계·컵 좌표 단위 검사를 보강했다. 추가 독립 리뷰 역할 실행은 런타임 thread limit으로 불가했으므로 독립 승인으로 기록하지 않는다. 컵 접근·닫기·들기는 아직 실물 미실행이다.

## 2026-09-29 | 핀 재연결 확인과 IK 관절 기준 분리

- 사용자가 빠진 핀을 재연결한 뒤 왼팔 6축 위치·토크·offset·범위·Phase·P·LOCK·상태 읽기가 복구됐다. 저장 보정과 일치하며 P16·LOCK1·전축 OFF였다. 재연결 전에는 포트 점유 없음, 200 ms 대기에도 왼팔 6축 무응답, ID 1/6 ping·위치 읽기의 수신 0 byte, 7개 호스트 통신 속도·ID 0–6 ping 무응답을 확인했다. 오른팔 6축은 같은 코드로 정상 응답했다. 핀 상태는 사용자 관측이며 이전 위치 미도달까지 같은 원인이었다고 단정하지 않는다.
- 새 snapshot과 7표본 명목 검토로 P16의 팔꿈치 3° 제한 시험을 1회 실행했다. 목표 raw 2483 대비 관측 2511, 시작 2517 대비 6 tick 이동 후 미도달이었다. 실패 기록·5초 영상은 로컬 `restaurant/calibration_20260929.BVaxly/left_pin_reconnected_physical01.json`·`left_pin_reconnected_clear_step01.mp4`에 보존했다. 종료 오류 없음·6축 OFF를 확인했다. 이후 사용자가 반복 진단 중단을 요청해 예정된 추가 P32 비교는 실행하지 않았다.
- 사용자는 접힌 손목·그리퍼가 책상에서 떠 있다고 확인했다. 현재 명목 모델의 책상 아래 링크 계산과 맞지 않으므로 실제 상판 접촉으로 판정하지 않는다. 기존 제한 시험은 3° 목표마다 4 tick(약 0.35°) 도달을 요구하고 종료 시 토크를 해제하므로 전체 접근 제어를 대체하지 못한다. 해당 시험의 실패 기준을 낮추거나 반복해 컵 접근 성공으로 표시하지 않았다.
- `servo/joint_reference.py`는 사용자가 정렬한 URDF 기준 각도와 읽기 전용 raw snapshot을 별도 영점으로 묶는다. 범위 midpoint를 영점으로 자동 재사용하지 않으며, calibration·URDF 해시와 관절 순서·출처를 대조한다. EEPROM·서보 설정을 변경하지 않는다. 기준 정렬 확인 없는 CLI 출력은 거절하며 사용자 정렬을 정밀도 검증으로 표시하지 않는다. 실제 기준 자세는 아직 확보하지 않아 실물 기준 파일을 생성하지 않았다.
- 선택한 기준은 IK snapshot·prepare·packet 검증·충돌 감사·Isaac 입력 변환·컵 상부 후보에 동일하게 적용된다. 기존 기준 없는 경로는 유지한다. `render_joint_reference.py`로 현행 메시의 왼팔 q=0 옆면·입체 참고 그림을 생성하고 확인했다. 그림은 자동 실행 자세 명령이 아니다. 독립 검토에서 임의 기준 각도 입력 문제를 발견해 등록 자세를 그림과 같은 q=0으로 제한하고 현행 URDF 한계·실제 해시를 대조하도록 수정했다. 새 기준의 왕복 변환·잘못된 해시·입력·snapshot 쓰기 금지·IK/시뮬레이션 일치를 포함한 관련 120개 검사와 pyflakes·diff 검사가 통과했고 독립 재검토도 승인했다. 실물 기준 정렬·접근 경로·컵 파지는 남아 있다.

## 2026-09-29 | 영상 재확인과 왼팔 통신 무응답

- 사용자 카메라 조정 후 상단·손목 RGB 3대의 실시간 연결을 확인했다. 상단 영상에서 컵·접힌 양팔은 보이지만 베이스 회전축과 상판 측면이 가려져 모델의 초기 낮은 링크가 실제 상판에 닿는지 판정하지 않았다. 별도 읽기 전용 영상 검토도 같은 한계를 확인했다.
- 왼팔 `5B3E088747`의 ID 1–6 위치·토크·목표·속도·P/D/I·LOCK·상태 읽기가 모두 무응답이었다. 포트를 다시 열어 ID 1 ping·위치·토크를 두 차례 확인해도 응답이 없었고, 오른팔 `5B3D046653`의 ID 1은 두 차례 정상 응답(raw 2062·토크 OFF)했다. 왼팔 USB 장치 경로는 유지된다. 전원·배선·버스 이상은 가설이며 토크 OFF 여부도 이번 왼팔 판독으로 확인할 수 없다.
- 이번 확인에서는 이동·토크·설정 쓰기와 온도·부하 읽기를 수행하지 않았다. 이전 P32 제한 이동 실패가 해결된 것으로 표시하지 않는다. 왼팔 전원·서보 케이블 상태를 확인해 통신을 복구한 뒤 새 snapshot부터 이어가야 하며, 컵 접근·닫기·파지는 미실행이다.

## 2026-09-29 | 팔꿈치 P32 제한 진단과 80 mm 컵 상부 준비 후보

- 사용자가 컵 잡기 전까지 구동 진단과 접근 준비를 진행하도록 승인했다. 닫아 잡기·상승·오른팔·베이스 이동은 실행하지 않았다. RGB 3대 영상 연결과 종료 후 왼팔 토크 6개 OFF를 확인했다.
- 제한 실행기에 `--elbow-p-test 32`를 추가했다. 기본은 기존처럼 P/LOCK에 쓰지 않는다. 시험은 별도 journal을 새로 확보하고 실물 보정·시작 raw·전축 OFF·ID3 P16/LOCK1을 확인한 뒤 백업을 fsync한다. P32 적용/readback/LOCK 복원 후 제한 동작을 수행하고 예외·인터럽트·ACK 실패에도 finally 복구한다. 전축 OFF와 unlock이 증명되지 않으면 P 복구 쓰기는 보류하고 `restore_pending`을 실패로 기록한다. 보호·offset·Phase·온도·부하에는 접근하지 않는다.
- P32 첫 시험은 ID1 토크 ON 쓰기 응답 실패로 목표 이동 전에 중단됐다. P16/LOCK1 복구와 전축 OFF를 확인한 뒤 제한 재시험했다. 두 번째는 목표 2482를 readback으로 확인했지만 관측 2498·오차 16 tick에서 미도달로 끝났다. 시작 2515 대비 약 1.5° 반응이며, P16의 같은 목표 시험에서 기록한 마지막 오차 29 tick보다 줄었다. 게인 영향은 관측됐지만 원인 확정·목표 도달·실물 접근 성공이 아니다. 양쪽 실패 및 gain journal은 로컬 `restaurant/calibration_20260929.BVaxly/left_clear_step_gain32_physical01/02.*`에 보존했다. 재시험 후 P16/LOCK1, 종료 오류 없음, 전축 OFF를 확인했다.
- `prepare_bench_cup_pregrasp.py`와 실측 YAML의 `nominal_pregrasp`를 추가했다. 80 mm 컵 메시 단면에서 접촉 중심을 균형화한 모델 후보는 `tool0=[-40.4,0,-20] mm`, 개방각 1.45 rad, 최소 반경 여유 약 2.85 mm다. 이는 실측 TCP·raw 개방 보정이 아니다. 80 mm 후퇴·몸통 높이 후보는 손목 한계로 수평 조건에 실패해 별도 보존하고, 활성 후보는 베이스 상대 `[270,0,170] → [350,0,170] mm` 상부 정렬로 바꿨다. 앞 해에서 이어 풀어 손목 180° 분기 전환을 피한다. 최종 후보의 양자화 FK 위치 잔차는 0.1482/0.6386 mm이며 모델 끝점 오차만 뜻한다.
- 별도 CPU 경로 검토는 이전 접촉 중심 후보04·명목 개방각 1.45·2° 보간 76표본에서 시작 5개 자가접촉이 해소되고 신규 쌍이 없음을 확인했다. 새 균형 중심 후보05나 실제 개방 raw의 경로 승인으로 재사용하지 않는다. 초기 보고의 과거 장면 평면 693.1 mm는 철회했다. 현재 가정 평면 726 mm 기준 시작 최저점은 약 25.863 mm 아래, 준비 자세는 약 16.2 mm 위다. 책상 XY 외곽·실물 원점·관절 영점·raw↔개구 대응이 미측정이므로 실제 충돌과 물리 경로 통과는 판정하지 않았다.
- 신규 준비 도구는 포트·그리퍼 raw 목표·닫기 명령을 생성하지 않는다. 결과는 `physical_execution_ready=false`, `start_to_endpoint_path_verified=false`를 유지한다. 후보05와 종료 후 snapshot `left_after_gain_trials01.json`은 로컬에 저장했다. 현재 영상은 베이스와 팔 전체가 잘려 있어 실물 원점·방향 대조에 필요한 관측이 부족하다. 상단 카메라의 표준 V4L2 줌·팬·틸트 제어를 읽기 조회했지만 모두 미지원(EINVAL)이었다. 소프트웨어로 해당 제어를 변경하거나 카메라 프로세스를 재시작하지 않았다. 제한 구동 미도달과 실제 기하 대응이 해결되기 전에는 큰 컵 접근을 실행하지 않는다.
- 복구·잘못된 원본 P·정지 실패·저널 실패·IK 준비 입력·양자화·분기 회귀를 포함한 105개 시험, pyflakes·diff 검사 통과. 별도 검토는 P 시험 복구와 소프트웨어 준비 도구의 차단 결함을 찾지 못했으며 전체 실물 IK·컵 파지 승인과 구분한다.

## 2026-09-29 | 제한 동작 도달 판정 수정 후 실물 재시험 실패

- 작은 중간 목표 간격(약 10 tick)이 도달 허용 오차(15 tick)보다 작아 움직임 없이 중간 단계가 통과할 수 있음을 확인했다. 기존 전체 실행 기본값은 유지하고, 제한 reset 시험만 같은 -34 tick 끝점을 한 번에 명령하며 허용 오차를 4 tick으로 적용했다. 목표·마지막 관측 raw·마지막 최대 위치 오차도 기록한다. 구동 프로파일·P/D/I·EEPROM·보호 설정은 변경하지 않았다.
- 같은 제한 범위 실물 재시험에서 목표 ID 3 raw=2482를 readback으로 확인했으나 마지막 관측은 2511, 오차 29 tick으로 `position_stall:CLEAR_RESET_STEP`이었다. 시작 실물 위치 2515 대비 약 0.35° 반응이며 완료 phase는 없다. 최종 토크 6개 OFF, 정지 오류 없음, 컵 파지 미실행이다. 실패 원본은 로컬 `restaurant/calibration_20260929.BVaxly/left_clear_step_physical02.json`에 보존했다.
- 신규 정지 모터 미도달·잘못된 실행 인자 쓰기 금지와 기존 IK·작은 개폐 회귀를 포함해 90개 시험, pyflakes·diff 검사가 통과했다. 별도 코드 검토는 같은 끝점의 제한 재시험에 차단 결함을 찾지 못했다. 소프트웨어 판정 수정으로 실물 구동 문제가 해결됐다는 뜻은 아니다. P=16에서의 구동 응답·기계 저항 등 원인은 여전히 미확정이며 P 변경 진단은 실행하지 않았다.

## 2026-09-29 | reset 자세 팔꿈치 제한 동작 미도달

- 사용자가 현재 자세가 reset이라고 확인해 옆모습 사진 요청을 철회했다. 현재 자세를 URDF 영점이나 과거 기체 home 값으로 재정의하지 않았다.
- `tools/servo/ik_reset_clear_step.py`는 기본으로 포트 없이 후보만 생성하고, 별도 실행에서 왼팔 ID 3만 -3°(34 tick) 목표를 준다. 다른 관절은 현재 위치를 유지하도록 토크를 켠다. 보정·URDF·시작 snapshot과 모델 검토를 묶고, 기록 경로를 확보한 뒤 실행한다. 모델 검토는 제한 동작의 명목 FK 상승과 신규 접촉 쌍 없음만 확인하며 실물 기하나 컵 파지를 인증하지 않는다.
- 실물 목표는 팔꿈치 raw 2516 → 2482였다. 중간 위치 기록은 2516 → 2514였고 `position_stall:CLEAR_RESET_STEP`으로 실패했다. 단계 완료 없음, 최종 왼팔 토크 6개 OFF, 정지 오류 없음이다. 약 0.2° 반응이며 컵 접근·파지 성공이 아니다. 실패 원본은 로컬 `restaurant/calibration_20260929.BVaxly/left_clear_step_physical01.json`에 보존했다.
- `servo-register-triage` 읽기 진단에서 왼팔 6축 P=16, 위치 모드=0, Goal_Time=0, Status=0, Moving=0, 잠금=1을 확인했다. 목표와 현재 위치는 종료 처리 후 값이므로 실행 중 목표 증거로 사용하지 않는다. 낮은 게인·마찰·구동 응답은 가설이며 원인은 미확정이다. P/D/I·보호·offset·Phase는 변경하지 않았고 온도·부하를 읽지 않았다.
- 제한 실행기 검증은 기본 포트 미접근, FK 변조·신규 접촉 거부, EEPROM 불일치 시 쓰기 금지, 종료 복원·OFF, 기록 실패 시 포트 미개방을 포함한다. 독립 코드 검토는 제한 동작에 차단 결함을 찾지 못했으며 실제 동작 성공이나 전체 IK 승인과 구분한다. 실물 컵 잡기와 현재 관절 기준의 기하 대응 검증은 남아 있다.

## 2026-09-29 | 실측 컵 상대좌표 확보와 현재 자세의 URDF 대조

- 사용자가 왼팔 베이스 중심에서 앞 350 mm·좌우 중앙, 컵 몸통 지름 80 mm·높이 100 mm, 팔과 컵이 같은 책상면이라고 알려줬다. `calibration/workcells/bench_cup_20260929.yaml`에 출처·날짜·단위·유효 배치와 미검증 항목을 분리해 저장했다. 이동 베이스의 `base_footprint` 좌표나 카메라 보정값으로 표시하지 않는다.
- 명목 `left_base_link` 원점과 책상면을 잠정 대응시켜, 순정 `tool0`의 상부 정렬·상부 준비·컵 위·컵 중간 수평 IK 네 후보를 계산했다. 각 후보의 모델 내부 위치 오차는 0.0039/0.0301/0.0008/0.0530 mm다. 수치 수렴이며 실물 TCP 오차·실물 파지 성공을 뜻하지 않는다. 실제 접촉 중심과 80 mm 컵에 필요한 개구는 아직 대조하지 않았다.
- 현재 왼팔 snapshot을 같은 명목 URDF에 대입하면 비인접 링크 접촉 5쌍, 그리퍼 링크 최저점이 가정한 책상면 아래 29.45 mm로 나온다. 실제 충돌 또는 관절 영점·장착 원점 불일치 중 어느 것인지 확정하지 않았다. 상단 영상에서 팔 전체가 잘려 있어 사용자에게 왼팔 옆모습을 요청했다. 이 상태로 큰 이동을 실행하지 않았고 범위 캘리브레이션도 반복하지 않았다.
- 실제 raw/torque snapshot과 상단 영상, 명목 검토 결과는 로컬 `restaurant/calibration_20260929.BVaxly/left_ik_snapshot01.json`, `top_ik_geometry01.jpg`, `bench_cup_nominal_review01.json`에 보존했다. 마지막 snapshot의 왼팔 6개 토크는 OFF다. 이번 컵 IK 검토는 포트 쓰기·실물 이동 없이 수행했다.
- IK 실행기에 대시보드 정지 감시를 대기 루프와 단계 입력 대기까지 연결했다. execute는 배타적 포트 개방을 사용하며 신호 취소가 cleanup을 중간에 끊지 않게 했다. 정지 시 전체 OFF → 현재 목표·프로파일 복원 → 최종 OFF 최대 3회 읽기 대조로 변경했고 한 ID 실패에도 나머지 정지를 시도한다. 온도·부하를 읽거나 보호 설정을 바꾸지 않는다. 실물 재시험은 현재 자세와 URDF 대응 확인 뒤 수행한다.
- IK·부분 개폐·실행 준비 회귀 94개, 구문·pyflakes·diff 검사와 컵 측정값·단위·출처 스키마 대조가 통과했다. 검증은 모의 실행과 파일 대조이며 이번 변경으로 실물 접근 성공을 주장하지 않는다.

## 2026-09-29 | 전원 재인가 후 보정 유지와 양팔 작은 개폐 확인

- 사용자의 전원 재인가 완료 확인 후 양팔 저장 범위·offset·Phase·LOCK와 12개 토크 OFF를 읽기 대조했다. 새 보정 JSON과 일치하며 오른손 Phase=76이 유지됐다. RGB 3대와 대시보드 정지 요청 API도 정상 연결이었다.
- `small_raw_jog.py`에 현재 보정 JSON의 6축 offset/limits 및 ID 6 Phase를 대조한 뒤 그리퍼만 128 tick 열고 시작점 기준 64 tick 위치로 부분 되닫는 경로를 추가했다. 왼손 drive_mode=0은 증가, 오른손 drive_mode=1은 감소가 열림 명령이다. 다른 관절은 켜지 않으며 온도·부하·EEPROM 설정에는 접근하지 않는다. 목표 위치 판정의 허용 오차는 16 tick이며 실제 죠 동작·파지 성공과 구분한다.
- 왼손 raw 1342 → 열림 목표 1470 → 부분 닫힘 목표 1406에서 위치 단계 통과, 최종 raw 1414·토크 6개 OFF·정지 오류 없음이었다. 오른손 첫 시험도 양방향 위치 단계는 도달했으나 마지막 토크가 1로 관측돼 종료 코드 2로 실패했다. OFF 1회 재전송 후 6개 OFF와 3회 읽기에서 raw=goal 1889, speed/accel=0, Phase=76을 확인했다. 원인은 확정하지 않았고 실패 원본을 보존했다.
- 종료 처리에서 설정 복원 뒤 OFF를 마지막 쓰기로 수행하고 최대 3회 읽어 대조하도록 보완했다. 오른손 제한 재시험은 raw 1889 → 열림 목표 1761 → 부분 닫힘 목표 1825로 위치 단계 통과했고, 최종 raw 1822·토크 6개 OFF·정지 오류 없음이다. 기존 왼손 시험과 오른손 재시험에서 다른 5축 위치는 변하지 않았다. 전체 끝점 개폐·컵 파지·TCP 검증은 수행하지 않았다.
- 실제 trial과 전원 재인가 후 preflight·해제 확인은 로컬 `restaurant/calibration_20260929.BVaxly/`에 저장했다. 핵심 결과는 `left_gripper_physical01.json`, `right_gripper_physical01.json`(종료 실패), `right_gripper_release01.json`, `right_gripper_after_release01.json`, `right_gripper_physical02.json`(재시험 통과)다. 짧은 손목 영상은 참고용이며, 전체 태스크나 양쪽 죠 동작의 검증 완료 영상으로 표시하지 않는다.
- 독립 code-reviewer가 제한된 개폐와 종료 처리의 차단 결함을 찾지 못했고 오른손 같은 조건 1회 재시험을 승인했다. 기존 손목 16개와 신규 그리퍼 15개를 포함한 범위·정지 관련 시험 71개와 IK 준비 시험 63개, 총 134개가 통과했다. 구문·pyflakes·diff·문서 링크 95개·README 자동 요약 검사도 통과했다. 실물 정지 상태 이상에는 `servo-register-triage`의 위치·목표·속도·토크 읽기만 사용했으며 부하·온도 및 보호 설정 변경은 제외했다.

## 2026-09-29 | 양팔 수동 범위 기록과 한계값 적용, 전원 재인가 대기

- 사용자가 왼팔·오른팔 수동 범위 기록 완료를 확인했다. 왼팔 순정 그리퍼 후보는 1340~2834 tick이며, 오른팔 ggao50은 관측 486~3456에서 양 끝 40 tick 여유를 둔 526~3416이다. wrist_roll은 0~4095 관례값으로 유지했고 롤 끝점은 수동 측정하지 않았다.
- `servo_apply_ranges.py`를 추가했다. 적용 전 EEPROM 백업·현재 offset·한계·Phase·토크 OFF·잠금·현재 위치를 대조하고, 사전 상태를 디스크에 저장한 뒤 MIN/MAX와 임시 잠금만 쓴다. ACK 유실도 변경 가능성으로 취급하며, 쓰기 실패·최종 대조 실패·중단 요청·결과 저장 실패 시 변경을 시도한 한계값을 복구한다. 복구 실패는 별도로 보고하고 성공으로 기록하지 않는다.
- 실제 양팔 사전 대조와 적용 후 대조가 통과했다. E 보드 왼팔과 D 보드 오른팔 각각 결과는 `applied_pending_power_cycle`이다. 12개 토크 OFF, 홈오프셋·Phase·P/D/I·잠금 보존을 확인했다. 오른손 ID 6 Phase=76이며 JSON 방향은 `drive_mode=1`이다. 온도·부하 읽기, 토크 ON, 이동 목표 쓰기는 없다.
- `calibration/bi_follower/arms_left.json`·`arms_right.json`을 적용 후보와 일치하게 갱신했다. JSON 오프셋은 보드의 현재 값을 반영했으며 보드 오프셋 자체는 변경하지 않았다. 리더·단일팔 과거 사본·LeRobot 캐시는 바꾸지 않았다. README와 보정 안내에 전원 재인가 후 읽기·개폐 검증 및 새 IK 목표 생성 조건을 반영했다.
- 원본 백업·후보·실물 적용 journal은 로컬 `/data/$USER/robot-artifacts/restaurant/calibration_20260929.BVaxly/`에 보존하고 Git에서 제외한다. 팔별 결과는 `left_apply01/journal.jsonl`, `right_apply01/journal.jsonl`에 있다. 범위 끝점은 사용자 수동 기록이며, 반복 끝점 측정이나 실물 파지 정밀도 증거로 해석하지 않는다.
- 신규 적용 시험 16개 포함 범위·손목·대시보드 시험 56개와 IK·준비 packet·상태 변환 시험 63개, 총 119개가 새 JSON 반영 후 통과했다. 문서 링크 95개·README 자동 요약·diff 검사도 통과했다. 독립 code-reviewer는 적용 도구·시험·안내의 차단 결함을 찾지 못했으며, LSP 도구 미제공으로 형식 판정은 COMMENT다. py_compile·pyflakes와 실제 readback으로 검증을 보완했다. 전원 재인가와 그리퍼 개폐 관측은 아직 남아 있고, 이번 적용으로 기존 손목 목표 미도달이나 컵 파지 문제가 해결됐다고 주장하지 않는다.

## 2026-09-29 | 수동 범위 재보정의 읽기 전용 후보 기록 시작

- 사용자가 LeLab 대신 리포 도구로 보정을 이어가도록 요청했다. 기존 offset을 우선 유지하고 실물 범위를 수동으로 기록한다. 홈오프셋·기체 한계·보정 파일 백업은 로컬 `restaurant/calibration_20260929.BVaxly/`에 보존했다. 시작 상태 12개 토크 OFF를 확인했고, E 보드 ID 6 Phase=12·D 보드 ID 6 Phase=76이다. 오른손 ggao50의 Phase는 변경하지 않았다.
- `servo_record_ranges.py --capture-only`를 추가했다. 이 모드는 포트를 배타적으로 열고 범위 후보만 새 파일에 저장하며 EEPROM·원본 보정 JSON을 변경하지 않는다. 그리퍼 방향·양 끝 margin을 후보에 적용한다. EOF·누락 ID·좁거나 잘못된 범위·encoder 큰 불연속을 확정하지 않으며 기존 후보를 덮어쓰지 않는다.
- 기존 EEPROM 적용 경로도 readback 실패 시 JSON을 저장하지 않도록 수정했다. 부분 EEPROM 변경의 자동 rollback은 아직 없으므로 이번 기록 작업에서는 `--execute`를 사용하지 않는다. 후보 기록만으로 보정 완료나 실물 정밀도 검증으로 표시하지 않는다.
- E 보드의 왼팔 후보 기록을 시작했다. 사용자가 베이스·어깨·팔꿈치·손목 굽힘·순정 그리퍼를 손으로 움직이는 단계다. wrist_roll 범위는 관례대로 0~4095이며 수동 끝점 기록에서 제외한다. 종료 후 후보 검토·기체 적용·실물 개폐 확인·양팔 JSON 반영은 아직 남아 있다.
- 신규 범위 검증·후보 저장 검사 14개, 손목·대시보드 검사 26개로 총 40개 통과. 구문·pyflakes·diff 검사 통과. 최종 캘리브레이션 파일과 EEPROM은 이번 준비에서 바꾸지 않았다.

## 2026-09-29 | 보정 파일 미사용 손목 한 축 실물 반응 시험

- 사용자가 작은 동작 시험 진행을 승인했다. `tools/servo/small_raw_jog.py`는 명시한 보드의 ID 5 손목 회전만 현재 raw +32 tick 후 원위치를 목표로 한다. 다른 축은 켜지 않는다. 초기 6개 토크 OFF·위치 모드·하드웨어 위치 한계·시작 안정성을 확인하고 토크 ON 전에 현재 위치 목표를 기록·대조한다. 보정 파일 변환·offset/EEPROM 쓰기·온도/부하 읽기는 없다.
- 실행 중 대시보드 정지 요청과 연결 실패를 감시한다. 정지 요청·신호·통신/미도달 실패에는 자동 복귀하지 않고 손목 OFF, 현재 위치 목표, 원래 속도·가속도 복원과 readback을 수행한다. SIGINT/SIGTERM은 cleanup을 중간에 끊지 않도록 요청으로 처리한다. 대시보드 자체가 점유 포트에 OFF를 보낼 수 없는 한계는 유지하며 이 시험기만 협조형 정지 감시를 제공한다.
- 실물 `5B3E088747` 보드의 초기 raw `[1996,790,2521,2780,959,1517]`, 손목 목표 991에서 위치가 978까지 변한 뒤 미도달/스톨로 중단됐다. 다른 5축 위치는 같고 최종 토크 6개 모두 OFF, 정지·구동 설정 복원 오류 없음이다. 왕복과 컵 집기는 완료되지 않았다. 원시 인코더 반응을 URDF 각도 기준 검증이나 파지 성공으로 해석하지 않는다.
- 읽기 진단: ID 5의 P=16, D=32, I=0, CW/CCW dead zone=1, minimum startup force=16, torque limit=500, 위치 모드=0이다. P 게인·마찰 등이 목표 앞 정지에 영향을 줄 가능성은 있으나 원인을 확정하지 않았고 설정을 변경하지 않았다.
- 실물 결과는 `/data/$USER/robot-artifacts/restaurant/small_wrist_jog_20260929/physical01.json`, 읽기 사전 확인은 같은 폴더 `preflight01.json`에 남겼다. 신규·대시보드 모의시험 26개, 구문·pyflakes·diff 검사 통과. 연구자 보조 검토에서 방향/이동량 고정과 cleanup 신호 처리 문제를 찾아 수정했으며 정식 독립 승인으로 과장하지 않는다.

## 2026-09-29 | 실물 RGB 3대 카메라 관제와 양팔 정지 버튼

- `tools/camera_dashboard.py`를 상단·손목 A/B 3개 영상과 사용자 클릭 토크 OFF 관제로 갱신했다. 현 연결의 USB by-path를 기본값으로 사용하고 `127.0.0.1:8770`에만 제공한다. 카메라 좌우 역할은 미확정이므로 A/B로 표시한다.
- 정지는 서로 다른 팔 포트 2개를 명시한 경우만 활성화한다. ID 1–6 전체에 torque OFF를 전송한 뒤 읽어 확인하며 일부 ID/포트 실패 시 나머지 정지도 시도한다. 이동·토크 ON·EEPROM·온도·부하 접근은 없다. GET과 미인증 POST는 팔 포트를 열지 않는다.
- 정지 결과는 `~/.local/state/bimanual-robot/dashboard-stop.jsonl`에 저장한다. 토크 OFF로 팔과 물체가 내려올 수 있고, 포트를 다른 제어기가 사용하거나 통신이 끊기면 정지를 보장하지 못한다. 하드웨어 전원 차단 및 실행기 연동 인터록을 대체하지 않는다. 이전 OFF 확인도 현재 상태를 보장하지 않는다.
- 검증: 정지·통신 실패·다른 팔 처리·로그 실패·HTTP 보호·잘못된 포트 개수 포함 mock 10개 통과, 구문·diff 검사 통과. 연구자 보조 검토의 포트 개수 결함을 수정했다. 공식 독립 승인으로 취급하지 않는다. 실제 브라우저에서 3개 영상 640×480 로드, 정지 버튼 활성화, 가로 overflow 없음 확인. 검증 중 실물 정지 버튼이나 이동 명령을 실행하지 않았다.

## 2026-09-29 | IK 픽앤플레이스 실행 전 전체 소프트웨어 준비

- `ik_pick_place.py`에 재정렬·접근·닫기·상승·이송·내려놓기·열기·후퇴 11개 phase를 연결했다. 기본은 포트 미접근이며 snapshot/execute만 명시 포트를 요구한다. 현행 보정 JSON·EEPROM·실물 팔은 변경하지 않았다.
- 보정·URDF·설정·packet 해시, 좌우 raw 기준, 6축 ID·단위·목표와 시작 상태를 묶는다. DEGREE에 gripper drive-mode 반전을 덧붙이지 않고, gripper percent는 방향을 적용한다. 양자화된 개구 끝점과 FK를 다시 검사하며 Python 환경 간 작은 부동소수 차이와 raw 불일치를 구분한다.
- 감독형 실물 실행기를 구현하고 mock으로 검증했다. 오른팔은 snapshot·waypoint 전 대조만 수행한다. 왼팔의 시작 위치·offset·토크, 목표 readback, 위치 발산·스톨·timeout과 단계 확인 거절을 처리하고 실패 시 다음 phase로 가지 않는다. 현재 위치 목표·torque off·speed/accel 복원과 readback 실패 기록을 포함한다. 사용자 요구에 따라 온도·부하는 읽지 않는다.
- `simulate_fixed_ik_pick_place.py`는 같은 packet의 양자화된 목표를 순정 죠 물리 시험에 전달한다. 반대손 두 개구도 CPU 감사 값과 맞췄고, 배치 판정은 최초 컵 위치가 아닌 목적 위치를 사용한다. 기존 실험 경로의 기본값은 보존했다.
- 초기 접촉·상승 유지 중 기울기·하강 지지 미관측 실패를 저장했다. 접근 거리·IK 수렴·명시 하강 여유를 수정하되 실패 판정 기준은 완화하지 않았다. 최종 `validated_plan.json`의 59개 목표·459개 로봇 경로 sample이 통과했고 양자화 후 최대 FK 오차는 0.5064 mm다. 이는 가정 모델 수치다.
- `validated_mock.json`은 11개 phase와 정지·복원까지 통과했다. `isaac_touchdown`·최종 코드 `isaac_final`은 10 g 강체 컵 집기·상승·10 mm 이송·내려놓기·분리를 통과했다. 유지 최소 상승 59.596 mm, 최종 책상 지지 0.0981 N·손가락 접촉 0 N이며 최종 tool 해시도 일치한다. 실물·RGB 인식·유동·컵 변형·완전 연속 충돌 검증은 아니다.
- 실행 전/후 성공을 분리한다. mock·모터 도달로 physical_grasp_verified/physical_task_verified를 참으로 만들지 않는다. 현행 실측 작업셀·TCP·개구 대응값은 아직 없어 템플릿을 비워 두었다. 연결만 하면 무조건 실행된다고 표시하지 않는다. 실물은 감독형 확인, Isaac의 자동 접촉 하강 정지는 시뮬레이션 전용이다.
- 검증: tools pytest 525개 통과·2개 skip, 이후 추가한 실측 미확인 packet 실행 거부 검사 포함 신규 파일 45개 통과. 구문·pyflakes·diff·README 자동 요약·수정 문서 47개 로컬 링크 검사 통과. code-reviewer 생성은 native thread limit으로 불가했다. 별도 검증 패스와 연구자 보조 검토를 수행했으며 공식 독립 승인으로 과장하지 않는다.
- 실행 절차: [IK 픽앤플레이스 실행 전 준비](docs/20260929_IK_픽앤플레이스_실행전_준비.md). 로컬 증거는 `/data/$USER/robot-artifacts/restaurant/ik_pre_execution_20260929/`에 보존한다. 새 영상 프레임·데이터셋·가중치는 만들지 않았다.

## 2026-09-29 | 최신 보정 재사용과 고정 좌표 IK 준비

- 사용자가 저장소 캘리브레이션을 최신 상태로 확인했다. follower JSON 값은 변경하지 않고 calibration README·기계 YAML·메인 README의 FinRay 재보정 필수 설명을 정정했다. 사용자 확인과 실측 TCP·정밀도 검증은 구분한다.
- `cup_pick_dry_run.py`에 카메라·YOLO를 사용하지 않는 고정 컵 XY 입력을 추가했다. 작업대 높이와 파지 높이는 명시 입력이며 수평 접근을 기본으로 한다. 기존 영상 검출 경로는 보존했다.
- `prepare_pick_execution.py`는 현행 보정 파일의 SHA-256·5축 순서·서보 ID·시작/목표 raw tick을 기록한다. 기존 실행기는 이 기록이 있는 입력을 실제 사용 보정과 대조하며 과거 미바인딩 입력은 유지한다. 재보정·EEPROM 쓰기·실물 이동은 수행하지 않았다.
- 합성 좌표 `(0.32, 0.17)` m, 작업대 0.72 m, 파지 높이 0.06 m의 수평 접근은 pregrasp 오차 84.91 mm·관절 여유 0도로 거절됐다. 이 좌표는 실물 컵 좌표가 아니며 실제 파지 실패나 보정 불량으로 해석하지 않는다. 한계를 넓히거나 성공으로 표시하지 않았다.
- 별도 합성 좌표 `(0.39, 0.17)` m, 작업대 0.72 m, 파지 높이 0.10 m는 pregrasp·grasp의 최대 FK 오차 0.18 mm·최소 관절 여유 24.03도로 충돌 검토 진입 조건을 통과했다. 이 수치는 모델 내부 계산이며 경로 충돌·실물 오차 검증이 아니다.
- 접근 계획 준비와 픽앤플레이스 완료를 구분한다. 현행 CLI는 pregrasp·grasp까지만 다루며 닫기·상승·배치·후퇴와 실물 비교 시험은 후속 작업이다.
- 검증: 관련 pytest 91개 통과, pyflakes·구문·diff·README 자동 요약·Markdown 94개 로컬 링크 검사 통과. 새 code-reviewer/verifier 생성은 native thread limit으로 실패했다. 기존 연구자의 읽기 전용 보조 검토 39개 테스트도 통과했으며 이를 공식 독립 승인으로 표시하지 않는다.

## 2026-09-27 | 완료된 대기 서버 정리와 순정 SO101 컵 접촉 재검증

- 완료된 웹 시험 서버 8765·8768·8769와 ROS IPC bridge 2개를 명령·작업 경로·주문 IDLE 상태를 확인한 뒤 SIGINT로 종료했다. Isaac은 실행 중이 아니었다. 8090 관제·JDAMR RViz·다른 세션은 유지했다.
- `/tmp` 경로가 사라진 두 SQLite DB·WAL을 열린 descriptor에서 복구했다. `integrity_check=ok`, session 13개·왕복 12개 command를 확인하고 API snapshot과 함께 로컬 `restaurant/runtime_cleanup_20260927/`에 보존했다. 데이터 파일은 삭제하지 않았다.
- `dock_roundtrip02`의 12단계 전체 성공과 473.892초 도크 복귀를 확인했다. main PR #55는 반영됐지만 README가 시험 중으로 남아 있어 결과와 구형 프록시 한계를 갱신했다.
- `cup_stock_so101_experiment.json`을 추가했다. 기본 80 mm 패드 경로는 보존하고, 별도 순정 모드에서 왼손 visual·collision·관성·회전 관절을 유지하며 가정 접촉 프레임만 로그 사본에 붙인다. 손목·반대 팔 등 컵의 비파지 링크 접촉도 실패로 검사한다.
- `stock_cup01`은 1.0 rad 열림에서 9.517초 조기 이동 죠 접촉으로 실패했다. 원본 형상·경로·판정 임계값은 유지하고 열림만 1.3 rad로 변경했다. 10 g·210 g 각각 초기 1회·출처 메타데이터 수정 중 2회·리뷰 수정 후 1회에서 파지·상승·내려놓기·손 분리를 통과했다. 최종 `stock_cup08_reviewed`·`stock_cup09_loaded_reviewed`의 도구 해시가 현재 파일과 일치한다. 동일 가정 장면의 재현 시험이며 일반 성공률이 아니다.
- 실패 레코드 `FAIL-20260927-0001`은 `stock_cup01/failure.json`에 보존하고 전체 스키마·의미 검사를 통과했다. 관측·가설·재시험을 구분하고 `eval_only`, 학습 제외로 기록했다.
- 리뷰에서 회전식·직선식 죠의 형상 출처 표시 조합 오류를 수정했다. 순정 SO101·패드는 rad, 오른손 평면 죠는 m만 허용한다. 최종 전체 Python 3.12 테스트 548개 통과·2개 skip. Isaac Python 3.11은 VTK가 없어 전체 수집 검사가 실패했으므로 전체 테스트 성공 근거는 Python 3.12 실행 로그로 한정한다.
- 독립 code-reviewer가 최종 코드·문서·실험 해시를 대조해 차단 코드 이슈가 없다고 보고했다. 해당 역할의 LSP 진단 도구는 제공되지 않아 형식 판정은 COMMENT이며 compileall·pyflakes·pytest로 보완했다. README 자동 요약·문서 94개 로컬 링크·diff 형식 검사도 통과했다.
- 이번 결과는 고정 베이스·강체 원통·가정 마찰·시뮬레이터 좌표 조건이다. 실물 보정·컵 변형·RGB 인식·자가충돌 전체 검사·물 유동은 미포함이다. 다음은 현행 순정 죠 입력을 양팔 물붓기·상판 운반·재파지에 연결하는 작업이다.

## 2026-09-22 | PR 알림 댓글 제거와 검사 통과 후 자동 병합

- `Auto PR`과 `PR policy`의 위험도 댓글 생성·수정을 제거했다. 분류 근거·해결 순서·재현 명령은 Actions 실행 요약에만 남긴다. 기존 자동 생성 본문의 반복 면책 문구도 제거했다.
- 구형 workflow 두 개는 원격에서 비활성화하고 `auto-pr-assist.yml`·`pr-assist.yml`로 교체한다. 오래된 브랜치의 구형 workflow도 다시 댓글을 생성하지 않도록 한다. 기존 위험도 댓글 10개는 로컬 백업 후 삭제했다.
- 위험도만으로 자동 병합을 제외하지 않는다. Draft를 제외한 PR은 `validate` 검사 통과 후 자동 병합을 예약한다. main의 필수 검사에 GitHub Actions `validate`를 연결하고 승인 인원 0·CODEOWNERS 미사용은 유지한다.
- PR gate 실패 시 실패한 단계에 맞는 수정·재검증 명령을 요약한다. `pull_request_target`은 기준 브랜치의 정책만 읽고 PR head 코드를 실행하지 않는다.
- 봇 댓글로 발생하는 구독자 알림 원인은 제거하지만, PR 생성·병합·Actions 결과의 플랫폼 기본 메일은 각 수신자 설정에 따른다. 전체 팀원의 이메일을 저장소 코드로 차단했다고 주장하지 않는다.
- 충전소 왕복 구현은 별도 `feat/isaac-dock-roundtrip` 작업 트리에 보존했으며 이 변경에 섞지 않는다.
- 로컬 전체 테스트 511개 통과·2개 skip, 정책 회귀 18개 통과, 문서 링크 94개·README 동기화·58링크/57관절 모델 계약 검사를 통과했다.

## 2026-09-22 | 영상 확인과 이전 성공 시험의 PNG 용량 정리

- 발표용 영상은 로컬 `/data/$USER/robot-artifacts/restaurant/cinematic_wide01/hold_flow_wide.mp4`(59.625초·1920×1080·24fps)다. 전체 동작 영상은 `plate_service02/plate_service_full.mp4`(283초)이며 둘 다 이전 촬영본이다. 최신 웹 주문 시험 `ipc_phase04`는 영상 프레임을 기록하지 않았으므로 이 영상들을 웹 연동 시험 촬영본으로 표시하지 않는다.
- 전체 MP4의 프레임 수·전체 디코딩과 실패 증거 참조를 확인한 뒤 `service03`, `service05`, `raised_service05`, `wide_service02`, `plate_service02`의 중복 PNG 원본 2,378개(4,094,353,488 bytes)를 삭제했다. 대상은 각 `frames`와 마지막 두 실행의 `detail_frames` 안에 있는 숫자 이름 PNG만이다.
- MP4·결과·계획·장면·최종 이미지는 남겼다. `cinematic_wide01`, `ipc_phase04`, 실패 은행 전체를 포함한 보호 파일 118개의 SHA-256이 정리 전후 일치한다. 실패 은행의 근거 31개도 독립 검토에서 해시 일치를 확인했다.
- `/data` 여유 공간은 약 4.1GiB에서 8.0GiB로 늘었다. 삭제한 원본 PNG는 보존 MP4에서 무손실 복원할 수 없다. 최신 발표 영상의 재편집용 원본은 보존했다.
- 정확한 삭제 경로·크기·해시와 사후 검증은 로컬 `/data/$USER/robot-artifacts/restaurant/cleanup_20260922_frames/manifest.json`, `result.json`에 남겼다. 실패 시험, 최신 실행 및 입력 자산은 삭제하지 않았다.

## 2026-09-22 | 웹 주문과 단일 Isaac 월드의 phase별 물리 실행 연결

- `simulate_restaurant_mobile.py --executor-socket`으로 같은 Isaac 월드에서 조작 9단계를 요청별로 실행한다. 단계 사이에는 물리 시간을 멈추고, 컵·병·물 입자 상태를 유지한다. socket thread는 요청을 받고 시뮬레이션 thread만 PhysX를 갱신한다.
- 완료 phase의 실관측을 ROS Action `message`와 웹 SQLite command에 함께 저장한다. 최종 성공은 전체 판정과 `result.json` 저장 뒤 반환하며, 증거 저장 실패도 Action·프로세스 실패로 처리한다.
- 실제 executor는 한 world에 한 mission만 허용한다. 요청 ID와 payload를 대조하고, 다른 executor의 socket을 덮어쓰지 않는다. timeout·취소의 최초 원인을 보존하며 중단 뒤 같은 world를 재개하지 않는다.
- 관제의 수동 phase 전진을 session backend에서 차단했다. 첫 executor 결과 뒤 화면·상태 파일에서 실제 Isaac 실행과 mock을 구분한다.
- 검증 범위는 과거 접촉 프록시를 이용한 1번 테이블 냉수 주문이다. `ALIGN_TABLE`에 주방 이탈·바퀴 주행·테이블 접근이 임시로 포함된다. 충전소 출발·복귀·충전, 여러 테이블·병 선택, 반복 주문의 물리 reset, 최신 순정 그리퍼의 물리 검증은 남아 있다.
- 코드·문서 독립 검토에서 차단 이슈 없음. 관련 테스트 89개, Python 구문·미사용 이름 검사, JavaScript 구문 검사, Markdown 링크 검사를 통과했다.
- 실제 웹 주문 `ISAAC-PHASE-004`가 9개 조작 Action과 전체 물리 판정을 통과했다. `ipc_phase04/result.json`은 `task_pass=true`, `failure=water_served`, 시뮬레이션 282.942초·벽시계 841.484초를 기록했다. 물 입자 918개 중 컵 642개·병 275개·외부 1개, 운반 중 추가 손실 0개, 검사 대상 환경·자가충돌 최대 접촉력 0 N, 접지 검사 PASS다. 입력·도구 SHA-256도 현재 파일과 일치한다.
- 근거는 로컬 `/data/$USER/robot-artifacts/restaurant/ipc_phase04/`의 `result.json`, `executor_phases.jsonl`, `web_orders.sqlite3`, `execution.log`에 보존했다. 실물·학습 정책은 사용하지 않았으며 액체 입자 수는 실물 용량 측정을 뜻하지 않는다.
- 앞선 `ipc_phase01`에서는 컵·병 파지 뒤 웹 취소를 보내 54.267초 시점 `POUR`의 `CANCELED`, `stop_confirmed=true`를 확인했다. 초기화 중 코드 보완으로 중단한 `ipc_phase02`와 기존 socket 재사용을 거부한 `ipc_phase03`은 성공 근거에 넣지 않는다.

## 2026-09-22 | PLANNED executor Python ABI 분리와 상태 보존 IPC

- Isaac Sim 5.1 환경은 Python 3.11, ROS 2 Jazzy `rclpy`는 Python 3.12 확장이라 같은 프로세스에서 로드할 수 없음을 재현했다. 두 runtime을 Unix socket JSON 계약 `planned_executor_ipc_v1`으로 분리했다.
- ROS Action 쪽 `planned_ipc_server`와 Python 3.11에서 실행되는 `planned_executor_ipc_mock.py`를 추가했다. mock은 `mission_id`별 다음 phase, request ID 멱등성, 단일 실행, 취소와 timeout을 유지한다.
- 웹 관제 `ros2-planned-session`에서 1번 테이블 냉수 주문이 9개 조작 phase를 같은 session으로 통과하고 충전소에 복귀했다. SQLite에는 phase별 Action 결과가 남았다.
- Action 실행 중 웹 취소가 executor session까지 전달됐다. executor·Action·주문이 `CANCELED`로 끝났고 관제 취소 뒤 온 결과는 `superseded=true`로 저장됐다.
- 현재 executor는 `simulator_accessed=false`인 상태기계 mock이다. 다음 단계는 `water_service_mission.py`를 phase 경계에서 멈추고 재개하도록 분리해 같은 socket 계약 뒤에 연결하는 것이다.

## 2026-09-22 | 검증된 PLANNED 산출물 Action backend

- `planned_artifact_server`를 추가했다. 성공한 Isaac Sim `result.json`의 도구·입력 SHA-256, 전체 성공 조건, 9개 조작 phase 표본을 다시 검사한다.
- 관제의 `ros2-planned-artifact` 모드는 phase마다 같은 검증 산출물의 판정을 Action으로 받고 결과와 artifact SHA를 SQLite에 저장한다. 시뮬레이터나 실물에는 접속하지 않는다.
- 현재 코드 해시와 일치하는 `cinematic_wide01` 근거로 1번 테이블 냉수 주문을 통과했다. 9개 조작 Action 뒤 주문 성공, 충전소 복귀, `IDLE_AT_DOCK`까지 확인했다.
- 검증 범위 밖인 2번 테이블 요청은 두 번 재시도한 뒤 `ALIGN_KITCHEN:ARTIFACT_TABLE_UNSUPPORTED`로 실패했다. generic Goal 거부 대신 실패 원인을 Action Result와 SQLite에 보존한다.
- 다음 4B 단계는 `water_service_mission.py`를 장기 실행 executor로 분리해 Isaac 월드를 한 번만 만들고 phase 사이의 물리 상태를 유지하는 작업이다.

## 2026-09-22 | 웹 관제와 ROS 2 조작 Action 연결

- `service_order_server.py`에 선택형 `ros2-mock` backend를 추가했다. 기본 `immediate` 모드는 유지하며, `ros2-mock`에서는 조작 phase만 `/execute_manipulation_skill` 결과를 기다린다. 주행·충전은 아직 immediate mock이다.
- Action 성공일 때만 관제 phase를 전진시킨다. 거부·서버 미응답·timeout·실행 실패는 failure code로 재시도 또는 주문 실패에 반영하고 전체 Action 결과를 SQLite command payload에 저장한다.
- 실행 중 웹 취소는 활성 Action Goal에 전달한다. 취소로 관제 상태가 먼저 바뀐 뒤 도착한 Action 결과는 `superseded=true`로 기록하고 phase를 다시 전진시키지 않는다.
- 웹 화면 상단에 CPU dry-run과 ROS 2 조작 mock을 구분하고, 진단 영역에 실행 backend·활성 Goal·최근 backend 결과를 표시한다.
- 통합 시험에서 냉수 주문 한 건이 조작 Action 9개를 모두 통과해 서빙·충전소 복귀·`IDLE_AT_DOCK`까지 완료됐다. 웹 취소는 Action `CANCELED`와 주문 `CANCELED`로 함께 종료됐다. 0.03초 timeout은 `ALIGN_KITCHEN` 두 번 실패 뒤 주문 `FAILED`와 SQLite 기록으로 남았다.
- 다음 단계는 기존 `water_service_mission.py`의 검증 phase를 mock 대신 실제 PLANNED backend로 연결하는 것이다.

## 2026-09-22 | ExecuteManipulationSkill ROS 2 Action·mock backend

- `hold_flow_interfaces`에 `ExecuteManipulationSkill.action`을 추가했다. request·mission·order·skill ID, 전략, phase별 backend·checkpoint, timeout을 Goal로 받고 현재 phase를 feedback으로 보낸다. Result에는 성공·취소·timeout, 실패 phase/code, 시작·종료 시각과 사람 개입 횟수를 남긴다.
- `hold_flow_mission`에 ROS import가 없는 계약 검증 계층, 관제 `manipulate` 명령 adapter, simulation mock Action server와 CLI client를 추가했다. mock은 `dry_run=true`만 받고 모터·카메라·Isaac Sim에 접근하지 않는다.
- ROS 2 Jazzy에서 IDL 생성과 두 패키지 빌드를 통과했다. Action 왕복 결과는 정상 `SUCCEEDED`, 0.03초 제한 `TIMEOUT/ABORTED`, 실행 중 취소 `CANCELED`로 분리됐고 세 경우 모두 요청·미션·주문 ID와 phase/backend를 보존했다.
- 계약 단위 테스트 7개와 `colcon test`를 통과했다. 현재는 웹 관제 명령을 수동 client로 보내는 경계까지이며 웹 runtime 대기·실제 PLANNED/ACT 실행기·취소의 hardware bridge 전파는 남아 있다.
- 계약과 재현 명령: [ExecuteManipulationSkill ROS 2 Action 계약과 mock 검증](docs/20260922_ExecuteManipulationSkill_ROS2_Action.md)

## 2026-09-22 | 웹 주문·Mission Queue·배터리 관제 dry-run

- 4개 테이블의 냉수·온수 주문을 받는 CPU 전용 관제 상태기계를 추가했다. 주문 ID 멱등 처리, 우선순위 큐, 한 개의 활성 Mission, phase 재시도·실패 종료를 검사한다.
- 현재 위치→주방→손님 테이블→충전소 경로와 조작 명목 소비량을 합산해 다음 주문 수행 여부를 정한다. 배터리가 충분하면 손님 테이블에서 다음 주방 Mission을 시작하고, 부족하면 충전소 복귀·충전 뒤 재개한다.
- 기존 4테이블 지도와 팽창 A*를 navigation command에 재사용했다. `navigate`, `manipulate`, `charge` 명령은 이후 Nav2·`ExecuteManipulationSkill`·도크 backend가 받을 계약이며 현재는 즉시 성공 dry-run이다.
- 로컬 HTTP API와 운영형 주문 화면을 추가했다. 4테이블 식당 지도, 현재 이동 경로, 11개 phase, 냉수·온수 주문, 큐, 누적 이력과 이벤트를 한 화면에서 확인한다.
- 주문·이벤트·실행 명령·최신 snapshot을 SQLite에 저장한다. 기본 경로는 `$HOME/.local/state/bimanual-robot/service-order-server/`이며 서버 재시작 뒤 활성 주문, phase, 배터리와 큐를 복구한다. JSON과 JSONL은 확인용으로 함께 남긴다.
- 이 구현은 실물·ROS 2·카메라·Isaac Sim에 접속하지 않는다. 인증·TLS·다중 로봇 배차·무선 복구·실제 충전 확인도 남아 있다.
- 실행법과 다음 adapter 경계: [웹 주문·Mission Queue·배터리 관제 dry-run](docs/20260922_웹주문_미션관제_dry-run.md)

## 2026-09-22 | 차체 완성 전 지도·박스 station·충전소 왕복 기준선

- 현재 JD-AMR을 완성 전 양팔 물 서빙 로봇의 선행 실물 베이스로 사용한다. 새 2D 지도 생성 뒤 시작 위치·방향을 `home_dock`, 박스 앞 정차 자세를 `kitchen_station`, `table_01` 같은 이름으로 교시하고, 저장 지도+AMCL+Nav2로 반복 운용한다.
- JD-AMR `feat/restaurant-service-destinations`의 `8e11564`에 `home_dock` 교시와 `지정 station별 도착 → 전면 박스 안정 관측 20초 → 다음 station → home_dock 위치·방향 복귀` 상태기계를 추가했다. 박스 관측기는 속도를 발행하지 않으며 서비스 launch에서 명시적으로 함께 기동할 수 있다.
- 목적지와 home은 같은 지도·Keepout 해시와 실시간 격자 신원에 묶인다. 내부 판정 목표는 위치 0.05m·방향 3°·정지 1초이며 외부 계측 정확도로 표시하지 않는다. 과거 `후진 → 회전 → 후진`은 충전소 복귀가 아니라 목적지 이탈 동작으로 재분류한다.
- JD-AMR 패키지 빌드, 관련 기능 테스트 102개, 변경 파일 flake8, 설치된 CLI·launch 인자 확인을 통과했다. 새 지도 생성, 실제 station 교시와 한 번의 전체 왕복은 남아 있다.
- 이 선행 시험은 실제 센서를 쓰지만 완성 기체의 전체 검증은 아니다. 실제 충전 접점·전류, 박스 종류 분류, 양팔 조작, 완성 차체 하중·정지 성능은 별도 게이트로 유지한다. 실행 순서와 이관 경계는 [차체 완성 전 지도 기반 서빙 왕복 검증](docs/20260922_차체완성전_지도기반_왕복검증.md)에 정리했다.

## 2026-09-22 | 기각 영상·임시 검수 데이터 정리

- 최종 넓은 구도 실행 `cinematic_wide01`과 재편집용 원본·결과·manifest는 유지했다. 실패한 `cinematic_service01`, 반복 확대 때문에 기각한 `cinematic_service02`, 두 실행의 로그·옛 테스트 로그·임시 QC 이미지는 `/data`의 활성 작업 경로에서 제외했다.
- 환경 안전 정책이 영구 삭제를 차단해 314 MB를 `/tmp/bimanual-robot-cleanup-20260922-cinematic/`에 격리했다. 현재 세션에서는 복구할 수 있으며 시스템 재부팅·임시 파일 정리 뒤에는 복구를 보장하지 않는다.
- 최종 `hold_flow_wide.mp4`의 SHA-256은 `6ab936c3cf4c70caf763241b34e7932d976386e9c226c35b9bbf5184b40ce2d2`로 유지됐고 전체 디코딩을 통과했다. 실패 은행과 이번 영상 작업 밖의 과거 시뮬레이션 근거는 건드리지 않았다.

## 2026-09-22 | 과도한 확대 제거·전체 기기 추적 재촬영

- 이전 소개 영상은 동작 검증과 별개로 사용자가 확대가 너무 많아 보기 어렵다고 기각했다. 준비·적재는 넓은 고정 화면, 주행·서빙은 전체 기기 추적으로 바꾸고 물 흐름만 4초 확대한다. 연속 줌·돌리·회전은 없애고 16개 자막 단계는 유지한다.
- 촬영 설정과 검증을 바꾸며 팔·베이스 제어와 물리는 유지한다. 기기 보수적 외곽의 화면 여백, 고정 렌즈·거리, 위치 이동 추적, 확대 시간 검사를 추가했다. 초기 30 mm 후보는 여백 검사를 통과하지 못해 넓은 26 mm로 수정했다.
- `cinematic_wide01`은 282.925초에 전체 서빙을 통과하고 1713프레임을 기록했다. 최종 컵 688·병 228·외부 2개 입자, 운반 중 추가 손실과 검출된 팔 자체·환경 접촉은 0이다. 도구 18개·입력 7개 해시가 현재 원본과 일치한다.
- 주행 추적 카메라가 주방 선반·화분 앞을 지나는 가림을 영상에서 확인했다. 화면 외곽 투영 검사로 가구 가림까지 보장할 수 없음을 기록한다. 원본은 보존하고, 샷별 선두 프레임 제외와 전체 샷 제외를 편집기에 추가했다. `service_cinematic_wide01_head_cuts.json`은 이 실행에 한정한 검수 결과이며 범용 카메라 가림 방지 기능이 아니다.
- 도구 테스트 353 passed·2 skipped 이후 편집 회귀를 추가하고 관련 21개 테스트를 통과했다. 별도 code-reviewer가 촬영 설정과 제외 프레임 매핑을 각각 승인했다. 실물은 사용하지 않았다.
- 최종 `cinematic_wide01/hold_flow_wide.mp4`는 59.625초·1431프레임·1080p24이며 확대는 3.917초 한 번이다. 원본 16개 단계 중 출발 단계를 제외해 출력은 15개 자막 단계다. 선반·화분 가림 제외로 주행/접근 화면은 2.208초로 짧아졌다. 전체 경로가 연속으로 보이는 추적 영상으로 표시하지 않는다. 실제 편집 프레임 검수·영상/음향 전체 디코딩과 manifest 해시 대조를 통과했다.

## 2026-09-22 | 제품 시연형 카메라 촬영·영상 편집

- 사용자 요청으로 16개 장면의 돌리·줌·주행 추적 카메라와 1080p24 촬영 모드를 추가했다. 물리·팔 계획·컵/물 위치는 변경하지 않는다. 모든 촬영 프레임의 요청 카메라, 관측 tick 시각, 상태, 배속을 기록한다.
- 기존 2fps 광각의 프레임 보간 대신 지정된 물리 tick에서 새 렌더를 촬영한다. 한 장의 임시 PNG를 인코더에 전달해 디스크에 전체 이미지 열을 쌓지 않는다. 최초 `cinematic_service01`은 비동기 PNG 쓰기 완료 전 읽기로 실패했고, PNG 종료 표식 확인 후 `cinematic_service02`를 완료했다.
- 편집기는 한글 제목·단계·배속·상시 시뮬레이션 표시와 생성 배경음을 넣는다. 카메라 전환 첫 프레임의 이전 구도 잔류를 확인해 컷 앞부분 제외와 원본 프레임 매핑을 편집 기록에 남긴다. 실물 시연이나 촬영 현장 음향으로 표시하지 않는다.
- `cinematic_service02`는 282.783초에 task/sequence/placement/ground 검사를 통과했다. 컵 688·병 230·외부 0개 입자, 운반 중 추가 손실 0개, 검출된 팔 자체·환경 접촉 최대 0 N이다. 최종 테이블 지지 0.755 N·양손가락 접촉 0 N이며 1699프레임을 촬영했다. 같은 장면 조건 1회의 시뮬레이션 결과다.
- 전체 CPU 414 passed·2 skipped, 별도 code-reviewer 검토를 통과했다. 도구 18개·입력 7개 해시를 대조했다. 촬영 도중 추가한 인코더 오류 종료 정리 수정은 단위 테스트로 검증했으며, GPU에 로드된 수정 전 두 모듈은 실행 디렉터리의 `executed_tools/`에 보존했다. 현재 소스 전체로 GPU를 재실행한 결과와 구분한다.
- 최종 `hold_flow_promo_final.mp4`는 69.458초·1667프레임·1080p24다. 16컷 시작의 이전 구도 잔류 2프레임씩을 제외했고 프레임 매핑·해시를 manifest에 남겼다. 영상 검수 중 밝은 배경의 자막 패널 누락을 수정했으며 실제 ffmpeg 픽셀 회귀를 포함한 관련 18개 검사와 추가 코드 리뷰를 통과했다. 최종 물붓기 확대·컷 시작 구도와 전체 영상/음향 디코딩을 확인했다. 영상은 `/data/lim/robot-artifacts/restaurant/cinematic_service02/`에 보존하고 Git에는 생성 코드·설정·문서만 반영한다.

## 2026-09-21 | 높은 받침 없는 상판 적재·재파지

- 사용자 요청으로 정확한 중앙 조건을 폐기하고 기존 상판의 양팔 사이 위치를 탐색한다. 후보는 상판 중심에서 앞 120 mm·오른쪽 90 mm, 컵 중심 높이 780 mm다. 원본 `flared03` URDF를 그대로 복사하며 팔 장착 이동·받침 링크 추가는 없다.
- 45개 격자 중 수직 IK 후보 8곳이 정지 팔 메시 접촉 검사를 통과했다. 컵을 포함한 probe는 다른 검사다. 초기 후보 01~04는 오른팔 고정 부품/위팔과 컵 접촉으로 기각했다. 병 복귀 후 오른팔을 세우는 `RIGHT_CLEAR`를 추가했다.
- probe05는 75 mm 인출 중 왼손목·어깨 충돌, 06/07은 40/50 mm 인출 뒤 상승 중 손끝·컵 재접촉으로 실패했다. 빈손 상승을 6개 경유점으로 나눈 08은 분리·재파지를 통과했지만 relift의 관절 보간이 컵을 오른팔 쪽으로 약 6 mm 이동시켜 위팔 접촉을 검출했다. loaded 상승/하강에도 6개 경유점을 넣었다.
- `plate_release09`는 48.5초 조건 1회에서 상판 지지된 빈 컵의 손 인출·대기·재접근·파지·상승·2초 유지를 통과했다. 최종 양쪽 손 접촉 3.769/3.774 N, 상판 접촉 0 N, 컵 기울기 0.275°다. 초기화 reset을 포함한 독립 probe이며 물붓기·전체 서빙 성공은 아니다.
- 실제 상판 4개 링크를 각각 검사하고 수직 지지력만 합산한다. plate 실행은 컵 기울기 2°를 실제 관측에도 적용한다. 목표 XY 기준 `placement_requirement_pass`를 추가하고 원점 중앙 성공 필드와 구분했다. 기존 높은 받침 분기는 보존한다.
- 별도 code-reviewer가 지적한 상판 접촉력 상쇄와 명목/실행 기울기 조건 차이를 수정하고 음성 테스트를 추가했다. 단일 seed 선행 IK가 일부 가능한 후보를 기각할 수 있는 탐색 한계와 로컬 모델 없을 때 통합 테스트 skip은 남는다. 가능한 모든 상판 경로의 탐색 완료로 표시하지 않는다.
- 실패 `FAIL-20260921-2001`~`2008`과 근거 24개 파일을 로컬 실패 은행에 보존하고 스키마·SHA-256을 검증했다. 모델·영상·실험 로그는 Git에 넣지 않는다.
- `plate_service01`은 122.05초 오른팔 정리 구간에서 병과 `right_gripper_base_link`의 0.062 N 접촉으로 실패했다. 컵 속 물 692개·병 226개·유출 0개였지만 전체 성공은 아니다. `FAIL-20260921-2101`에 근거 3개를 보존·검증했다. 오른손을 6단계로 120 mm 수직 상승한 뒤 세우는 경로를 추가했다.
- `plate_service02`는 282.875초 조건 1회에서 물붓기·상판 적재·손 분리·주행·재파지·손님 테이블 배치까지 통과했다. `task_pass/placement_requirement_pass/ground_verified=true`, 정확한 중앙이 아니므로 `center_requirement_pass=false`다. 최종 물은 컵 684·병 230·바깥 4개, 운반 중 추가 손실·검출된 팔/환경 접촉 0이다. 테이블 지지 0.750 N, 양손가락 접촉 0 N, 손 이격 102.8 mm를 확인했다.
- 전체 CPU 397 passed·2 skipped, pyflakes·diff 검사와 도구 17개/입력 6개 해시 대조를 통과했다. 별도 리뷰에서 오른손 수직 인출의 새 차단 문제는 없었다. 566프레임을 녹화했으며 실물·Nav2·ROS BT·충전소 복귀는 검증하지 않았다. 원본 상판과 팔 장착은 유지한다.
- 283초 전체·70.75초 4배속·33초 상판 적재 확대 영상을 생성해 전체 디코딩을 통과했다. 기존 광각 렌더를 잘라 확대한 영상은 세부 해상도의 한계를 유지하며 실제 실행 증거와 구분하지 않은 생성 이미지를 쓰지 않는다.

## 2026-09-21 | 넓은 고정 화면과 물붓기 동기화 확대 녹화

- 기존 후방 사선 구도에서 오른팔·그리퍼가 컵 입구를 가리는 것을 확인했다. 발표용 카메라 설정을 별도 JSON으로 옮기고 1600×900 고정 전체 화면과 앞쪽 상단의 물붓기 확대 화면을 같은 물리 tick에서 기록한다. 실물 카메라·팔·주행 제어·물성을 변경하지 않았다.
- `wide_service01` 확대 63/65초 프레임에서 병 주둥이·컵 내부·공중의 파란 PBD 입자가 분리돼 보이는 것을 주 작업자와 별도 vision 에이전트가 확인했다. 초기 전체 구도는 통과했지만 후반 검수에서 기각했다.
- 카메라 선택·설정 불변성·잘못된 값 거부·합성 시점과 누락 프레임 검사를 추가했다. 전체 CPU 384 passed·2 skipped와 pyflakes를 통과했다. code-reviewer 추가 생성은 호스트 thread limit으로 실패해 정식 독립 코드 승인이라고 표시하지 않는다.
- `wide_service01`은 273.367초에 물리 서빙을 통과했지만 테이블 접근에서 바퀴 쪽 여백 부족·화분 가림을 발견해 전체 카메라는 기각했다. 물은 컵 684·병 230·바깥 4개 입자다. 높이 4.3 m·거리 증가·16 mm 광각으로 바꾸고 로봇 외곽의 주방/후진/테이블 위치 화면 투영 검사를 추가했다. 이 검사는 기존 구도에서 실패하고 수정 구도에서 통과했다.
- 최종 `wide_service02`는 273.308초에 task/sequence/center/ground를 모두 통과했다. 컵 691·병 225·바깥 2개, 운반 중 입자 손실 0개, 검출된 자체/환경 접촉 최대 0 N이다. 도구 17개·입력 6개 해시를 대조했다. 물붓기 확대 127장(40~103초), 전체 547장을 기록했다. 초기·후반 광각을 별도 vision 에이전트와 검수했고, 최종 테이블 내려놓기 화면도 확인했다. 운반 중 컵은 전체 화면에서 작게 보이는 한계가 있다.
- `/data/lim/robot-artifacts/restaurant/wide_service02/`에 전체 합성 `water_service_wide.mp4`(273.5초), 4배속 `water_service_wide_4x.mp4`(68.375초), 확대 `pour_detail_55-85s.mp4`(30초)를 저장했다. 모두 1600×900이며 전체 디코딩을 통과했다. 실물·원본 URDF·동작 로직은 변경하지 않았다.
- 사용자가 받침 대신 상판 적재 가능성을 물었다. 상판 정확한 중앙 후보의 기울기·자체 충돌 실패와 상판 전체의 불가능성은 구분한다. 받침 없는 후보는 적재 위치·손 인출·재파지를 함께 재탐색해야 하며, 이번 카메라 검증에서 받침을 삭제하거나 경로를 변경하지 않았다.

## 2026-09-21 | 중앙 받침 운반·재파지를 포함한 연속 물 서빙 통과

- 최종 `raised_service05`는 273.392초 조건 1회에서 물붓기→병 복귀→중앙 받침 적재·손 분리→주행→정지→재파지→손님 테이블 내려놓기를 통과했다. task/sequence/center/ground 모두 true, 프로세스 종료 코드 0이다. 최종 물은 컵 688개·병 230개·외부 0개, 운반 중 물 손실 0개다. 검출된 자체·환경 접촉 최대값은 0 N이다. 최종 컵 위치는 (−2.134322,−2.411907,0.780000) m, 손가락 접촉은 양쪽 0 N, 손 이격은 102.795 mm다. 실물·Nav2·충전소 복귀는 포함하지 않는다.

- 실물은 보류하고 원본 URDF를 보존했다. 왼팔과 고정판의 후방 이동·yaw 후보를 실험 사본에만 적용하고, 상판 경계와 주방·중앙 IK를 검사하는 `search_tray_mounts.py`를 추가했다. 상판 높이 유지 30개 조합은 CPU 조건을 통과하지 못했다. 중앙 받침 160/200 mm와 후방 0/20 mm·yaw −15/0/+15°의 12개 비교에서는 8개가 중앙 XY 20 mm·높이 2 mm·기울기 2° 조건을 통과했다. 불가능성 증명이나 메시 충돌 인증은 아니다.
- `static-pose-probe`는 안전 자세→기존 충돌 자세→안전 자세 대조군에서 충돌 후보만 검출했다. 원래 장착에서 높인 중앙 위치에 해당하는 네 자세의 팔 자체 충돌은 검출되지 않았다. 정지 초기화 시험이며 컵·받침과 연속 이동은 포함하지 않는다.
- 후방 20 mm·yaw 0°·받침 160 mm 사본에 판·기둥의 충돌/관성 요소를 추가하고 전체 물붓기 IK를 재계산했다. `raised_service01`은 컵 691/918·외부 1개 입자를 유지하며 중앙까지 이동했고 자체·환경 충돌은 0이었다. 컵이 받침보다 0.281 mm 떠 지지력 0 N인 채 하강이 끝나 실패했다. 기존 설정의 2 mm 접촉 여유와 지지 감지 시 관절 유지, DEPOSIT/손님 테이블 지지 높이 구분을 반영했다.
- `raised_service02`는 중앙 지지·그리퍼 열림·해제 유지까지 이어졌지만 수직 인출 중 컵과 다시 접촉했다. 133.742초에 컵 기울기 8.292°와 받침 높이 조건 위반을 검출해 실패했다. 물은 컵 689개·병 227개·외부 2개였다. 134초·268프레임·1280×900 영상의 전체 디코딩을 확인했다. 최종 손 분리·운반 완료로 표시하지 않는다.
- 160 mm 높이에서는 동일 높이의 75 mm 수평 후퇴점이 관절 한계에 걸렸다. 현재 후보는 후방 20 mm·yaw 0°·받침 200 mm다. 양수 손목 롤 분기를 유지하는 수평 후퇴→상승과 역순 재접근을 계산했고, 하강 접촉 여유는 적재에만 적용한다. 재파지는 수직 안착한 컵 중심을 목표로 한다. `raised_service03`은 수평 인출 뒤 PARK 복귀 중 컵과 다시 접촉해 실패했다.
- 접촉 관절값으로 해제 구간을 갱신해 WITHDRAW 시작의 2 mm 되돌림을 없앴다. 해제 후 재접촉 검사를 추가하고, `[0.20,0.17,1.08] m` 전방 상부 경유점을 넣어 PARK와 재접근을 우회한다. 빈 컵 분리 시험 `released_probe01`은 기존 PARK 실패를 재현했다. `released_probe02`의 그리퍼 파지 오차를 팔 추종 오차로 취급한 검사 오류를 수정했고, `released_probe03`은 48.5초에 인출·PARK·재파지·2초 파지 유지까지 통과했다. 최종 양쪽 손가락 접촉은 4.017/4.013 N, 받침 접촉 0 N, 컵 기울기 0.068°다. 초기화 뒤 컵 위치 덮어쓰기·부착은 없지만 빈 컵 독립 구간 시험이므로 전체 서빙 성공은 아니다.
- `raised_service04`는 물붓기→중앙 적재·손 분리→주행까지 이어졌지만 최종 정렬에서 360초 시간 초과로 실패했다. 컵 683개 입자·운반 중 손실 0·자체/환경 접촉 0 N·접지 검증 true다. 바퀴축 목표 오차 5 mm의 제어 분기에서 회전 명령이 반전했고 마지막 60초의 600표본 중 295회 방향이 바뀌었다. 극좌표 제어와 방향 제어를 거리 제곱 가중치로 연속 혼합하도록 수정했다. 4~6 mm 경계 검사와 바퀴 지연·좌우 이득 차이를 포함한 주행 14개 테스트가 통과했으며 도착 허용 오차는 유지한다. 재실행05는 225.8초 경로 도착, 229.883초 정렬 종료, 230.383초 재파지 진입으로 이어졌다.
- 입력 모델/탐색 원본 해시를 대조하고 재계산 모델 provenance를 갱신했다. 초기 입력01의 오래된 provenance는 실패 원본으로 보존했다. 재파지 START/PREGRASP_ABOVE에도 조기 접촉 검사를 적용하고, 받침 상단의 허용 상태·중앙 위치·높이·양의 수직 접촉력을 검사한다. 받침 질량 75 g·강성·제작성은 미검증 가정이다.
- 별도 executor의 읽기 검토에서 하강 여유·지지면 높이·provenance·재파지 시작 검사 누락을 찾아 수정했다. code-reviewer 생성은 호스트 thread limit으로 실패했으므로 정식 독립 승인이라고 표시하지 않는다. 대용량 입력·영상·관측은 `/data/lim/robot-artifacts/restaurant/`에만 보존하며 push는 수행하지 않았다.
- 전체 CPU 379 passed·2 skipped, 강화된 주행 회귀 14 passed, pyflakes·diff 검사를 통과했다. 별도 읽기 검증에서 최종 상태·중앙 운반·재파지 2초 유지·테이블 손 분리와 코드 15개/입력 5개 해시 일치를 확인했다. 전체 영상은 547프레임·273.5초·1280×900이며 전체 디코딩을 확인했고 4배속 영상도 생성했다. 정렬 실패 `FAIL-20260921-1004`는 원인 확정·같은 장면 재시험 PASS로 기록하고 근거 4개 해시를 검증했다. 다른 장면 GPU 회귀가 없으므로 실패 은행의 상태는 `confirmed`이며 BC 편입은 false다.

## 2026-09-21 | 물붓기·중앙 적재·재파지 서빙 연결과 자체 충돌 확인

- 완료 조건을 물붓기 → 병 복귀 → 상판 중앙 컵 적재·손 분리 → 주행 → 재파지 → 손님 테이블 내려놓기로 수정했다. 빈 컵을 잡은 채 운반한 기존 시험은 최종 서빙 완료가 아니다. README와 식당 실행 문서에도 구분했다.
- `water-service` 개발 모드에 병·PBD 물 입자·상판 지지·재파지·수직 안착 검사를 연결했다. 실물 포트·ROS·카메라에는 접근하지 않았고, 초기화 뒤 컵·물 좌표를 덮어쓰거나 고정 조인트로 붙이지 않는다. 용기 부착 조인트 검출과 접촉 링크 기록을 추가했다.
- `water01`~`water04`는 초기 스냅샷과 물 입자 배치, 작업대 접촉 설정, 안정화 전 관측을 점검한 실패 기록이다. 병과 물은 같은 원본 스냅샷에서 가져오며 팔 접근 전 2초 안정화 후 조기 접촉·변위의 기준을 잡는다. 허용 변위 임계값은 늘리지 않았다.
- `water05`는 물붓기·병 복귀까지 이어졌고 컵 684개·병 233개·외부 1개 입자였다. 적재 경로의 반대 손목 분기 전환으로 118.725초에 컵 기울기 15.39°를 검출해 중단했다. CPU 보간 검사는 이 옛 경로의 최대 기울기 약 90°를 기각한다. 119초·238프레임 실패 영상의 디코딩을 확인했다.
- 같은 손목 분기에서 중앙 XY 20 mm 영역·최대 기울기 15°를 조건으로 새 IK 후보를 계산했다. 바닥 모서리 지지는 선택 옵션이며 그리퍼 해제 후에는 기존 수직 안착 기준 3°를 유지한다. `water06`은 122.725초에 왼팔 손목↔어깨 접촉 신호 17.13 N으로 실패했다. 물은 컵 687개·병 228개·외부 3개였다.
- `center_endpoint_probe`는 후보 관절값으로 정지 초기화한 대조 시험이다. 첫 스텝에서 왼팔 하완·손목과 어깨의 겹침을 확인했다. 바퀴 속도는 0이며 초기 관통 해소 충격을 실물 힘으로 환산하지 않는다. 해당 중앙 후보는 기각했고 충돌 필터를 추가하지 않았다. 가능한 모든 배치·경로가 불가능하다는 증명은 아니다.
- `water06`의 중앙 판정 보조 필드가 목표 좌표만 검사하던 문제를 발견했다. 현재 코드는 실제 적재 관측 1초와 중앙 영역 유지를 요구한다. 옛 결과는 전체 실패 상태로 보존하며 보조 필드를 중앙 안착 성공으로 인용하지 않는다.
- 전체 CPU 363 passed·2 skipped 후 중앙 관측 회귀 테스트를 추가했고 관련 23개 검사를 통과했다. 구문·pyflakes·diff 검사도 수행했다. 별도 탐색 에이전트의 읽기 검토는 받았지만 정식 code-reviewer 생성은 호스트 thread limit으로 실패했으므로 독립 승인이라고 표시하지 않는다.
- 남은 일: 충돌 없는 중앙 적재 자세·경로 확정, 필요 시 팔 장착 위치 또는 컵 거치 높이 설계 변경, 이후 독립 상판 운반·재파지·손님 테이블 안착의 연속 물리 검증. 중앙 적재 이후는 코드 연결만 있으며 완성 시연이 아니다. 로컬 증거: `/data/lim/robot-artifacts/restaurant/water01`~`water06`, `center_endpoint_input`, `center_endpoint_probe`.

## 2026-09-21 | 식당 자유 베이스 주행·빈 컵 운반·테이블 내려놓기

- 식당을 8.5×7 m, 손님 테이블 총 4개·의자 8개로 확장했다. 정적 지도 170×140 cell, 테이블별 왕복 12구간, 가구 충돌체 81개를 같은 설정으로 생성한다.
- 이동 실행기는 URDF를 자유 베이스로 import하고 바퀴 속도만 명령한다. 빈 컵 파지·후진·A* 경로 추종·테이블 정렬·실제 차체 정지·지지 확인·그리퍼 해제·손 후퇴를 연결했다. 초기 배치 이후 로봇/컵 좌표 덮어쓰기나 물체 부착은 없다. 실물·카메라·ROS에는 접근하지 않았다.
- 최종 `service05`는 115.6초 조건 1회에서 task_pass/ground_verified true, 종료 코드 0이다. 컵의 최종 중심은 (−2.13435, −2.41170, 0.78000) m, 손 이격 약 103 mm이며 양쪽 손가락 접촉이 해제됐다. 같은 실행의 232프레임·116초 영상을 기록했다. 앞선 `service03/04`와 최종 실행의 코드 버전은 각 해시·실행 사본으로 구분한다.
- 매 물리 스텝에서 가구·가동 링크·컵·예상 밖 바닥 접촉을 검사한다. 양 바퀴 각각과 캐스터 하나 이상의 지지는 0.5초 관측창·차체 높이·기울기로 검증한다. 동일 fixed-joint 조립체 내부 596쌍과 기존 랙 프록시 한 쌍만 충돌에서 제외하며, 가동 관절 경계와 외부 물체는 유지한다.
- 실패 원본은 `/data/lim/robot-artifacts/restaurant/`에 보존했다. 초기 주행 정차 오차, 접촉 API 인자 오류, PLACE 전환 시 이전 명령 재사용, 고정 구조물 내부 접촉, 예외의 성공 플래그 잔류를 수정했다. 단위 테스트로 고정 연결성·바닥 접촉·오류 플래그를 검사한다.
- `probe02`는 주입 장애물 접촉을 식별해 미션 실패/검출 시험 통과로 종료했다. 물리 제동 거리나 동적 장애물 회피를 검증한 것은 아니다. Kit의 graceful 종료 스레드가 남는 현상은 결과 저장 후 반환 코드와 함께 종료를 요청하도록 수정했다. 시간 초과 `exit_failure01`은 종료 코드 1, `probe02`는 종료 코드 0을 확인했다. 이미 끝난 옛 실행의 종료 잔여 프로세스만 정리했으며 산출물은 보존했다.
- CPU 전체 354 passed·2 skipped, 구문·pyflakes·diff 검사 통과. 별도 코드 리뷰의 미해결 차단 사항은 없으며, LSP 진단은 환경에 없어 실행하지 못했다. 기록된 실행 코드 사본·12개 도구·5개 입력 해시로 버전을 구분한다.
- 현재 물리 서빙 검증은 `table_1`의 빈 컵이다. 나머지 테이블은 정적 경로 검사만 수행했다. Nav2·ROS BT·SLAM, 물붓기와 액체 운반 통합, 충전소 복귀·실물 전이는 미검증이다. [실행법과 증거](docs/20260921_식당_시뮬레이션_환경.md)를 참고한다.

## 2026-09-21 | 입구 확장 컵과 발표용 식당 환경

- 컵 가운데 파지 지름 70 mm·높이 120 mm는 유지하고 입구 외경을 90 mm로 넓혔다. 높이별 반경을 시각 메쉬·속 빈 충돌체·물 입자 내부 판정에 함께 적용한다. 실물·카메라·ROS 접근은 없다.
- 25 mm 접근 `flared01`은 입구 접촉 뒤 추종 오차로 중단됐다. 45 mm `flared02`는 기존 판정을 통과했지만 조기 접촉 최대 43.364 N을 별도 리뷰에서 발견해 기각했다. 기록 재판정도 실패하며 원본 result와 별도 review_verdict를 보존한다. 실패 레코드 `FAIL-20260921-0004/0005`와 근거 6개는 `/data/lim/robot-artifacts/pour_20260921/failures/`에 있으며 스키마·SHA-256 검증을 통과했다.
- 닫기 전 접촉·컵 이동을 실행 중단과 최종 판정에 연결했다. 사전 접근 75 mm 후보는 하강 구간 241점의 양 패드·컵 벽 SAT 검사에서 최소 14.033 mm 분리됐다. 현재 경로 통과와 옛 45 mm 경로 실패를 회귀 테스트로 남겼다. 전체 연속 충돌 검증·실물 공차 보증은 아니다.
- 6×7 m 식당 USD·정적 지도·두 테이블 왕복 A* 경로를 추가했다. 가구·조명은 코드로 생성하고 마루 색상은 Poly Haven CC0 1K 재질을 사용한다. 51개 가구 충돌체의 월드 XY 외곽과 지도 장애물의 포함 관계, USD 재개방을 확인했다. 베이스는 정지 참조이며 Nav2·BT·운반·전체 서빙 통합 성공으로 표시하지 않는다.
- `flared03` 105°·20초 조건 1회는 종료 코드 0, task_pass/preclose_clear true로 파지·붓기·복귀·손 분리까지 통과했다. 최종 컵 631/918개·밖 3개이며 이전 원통 컵의 밖 8개보다 적다. 컵과 접근 경로를 함께 바꾼 단일 실행 비교다. 조기 접촉/이동 위반 0건, 비파지·팔끼리·용기끼리 접촉 신호 최대 0 N, 복귀 XY 오차 컵 2.559 mm·병 2.285 mm다. 도구 9개·설정 해시를 대조했고 1,308프레임을 기록했다.
- CPU 337 passed·2 skipped, 구문·pyflakes·diff 검사 통과. 코드 리뷰에서 발견한 조기 접촉 판정 누락과 장면/지도 원본 분리를 수정했다. 원본 URDF·실물 그리퍼 모델은 변경하지 않았으며 미보정 강체 프록시·8 mm 장착 가정은 유지한다.
- 식당 최종 `presentation02`의 전체·손님·작업대·컵 근접·상부 시점 렌더와 USD 재개방을 확인했다. 근접 카메라 near clip을 보정하고 상부 시점 잘림을 수정했다. `flared03/bimanual_pour_full.mp4`는 130.8초·1,308프레임·10 fps이며 전체 디코딩을 통과했다. 대용량 자산은 `/data/lim/robot-artifacts/`에만 보존한다. 원본 import의 빈 base visual 참조 경고는 문서에 남겼다.
- 실행법과 범위: [식당 환경](docs/20260921_식당_시뮬레이션_환경.md), [넓은 입구 컵](docs/20260921_양팔_PBD_물붓기_시뮬레이션.md#입구가-넓은-컵).

## 2026-09-21 | 오른쪽 병 몸통 유지·왼쪽 컵 방향으로 물붓기 경로 수정

- 사용자 영상 피드백으로 기존 `final_record03`의 경로를 기각했다. 기존 수치 통과와 별개로 병 몸통은 +Y(왼쪽), 입구는 −Y(오른쪽)를 향했다. 접촉 신호는 0 N이므로 측정 충돌로 바꾸지 않고 방향·팔 역할 실패로 기록한다.
- 오른손 초기 주차·파지를 음수 손목 롤 분기로 변경하고 입구가 컵 오른쪽 100 mm에서 왼쪽으로 접근하도록 했다. +Y 중심 ±30° 방향 범위와 몸통 오른쪽 배치를 필수 검사한다. 방위각 하나를 고정해 생긴 90° 부근 관절 급변은 범위 안의 연속성 비용으로 수정했다. 원본 URDF·실물·카메라·ROS는 변경/접속하지 않았다.
- `inward02` 105°·20초 조건 1회는 물 전달·복귀·손 분리까지 PASS, 종료 코드 0이다. 컵 626/918개(68.192%, 명목 40.064 mL), 밖 8개(0.871%)다. 15° 이상 붓기·복귀 관측 4,990개는 모두 요구 방향을 유지했고 병 중심 Y는 −126.16~−92.80 mm였다.
- 팔끼리·비파지 링크와 용기·컵과 병의 접촉 신호 최대는 0 N이며 연속 무충돌 증명은 아니다. 양손 접촉 유실 0초, 최종 복귀 XY 오차 컵 2.363 mm·병 1.893 mm다. 강체 프록시·추가 8 mm 장착 가설은 유지하므로 실물 성능으로 표시하지 않는다.
- 기존 반대 방향은 현 evaluator에서 실패한다. 회귀는 파지 분기·오른손 속도·몸통 오른쪽 유지·입구 왼쪽 이동·실제 쿼터니언 방향 검사를 포함한다. 전체 CPU 323 passed·2 skipped, 실행 도구 9개 해시 일치를 확인했다.
- 전체 녹화 130.8초와 실행별 근거는 Git 제외 `logs/pour_20260921/inward02/`에 보존한다. 전체·확대 영상 디코딩을 확인했다. 홈 용량 관리를 위해 완료된 프레임 2,737개와 나머지 실행 로그를 `/data/lim/robot-artifacts/pour_20260921/`로 이동하고 기존 경로 링크를 유지했다. 로그 이동 전후 2,268파일·2,870,635,708바이트의 상대경로·내용 합성 SHA-256이 일치했다. 홈 여유 공간은 2.5→6.2 GB이며 원본 삭제는 없다.

## 2026-09-21 | 양팔 파지·PBD 물붓기·원위치 복귀 전체 시뮬레이션 통과

- `simulate_bimanual_pour.py`와 CPU IK 시간 계획을 추가했다. 왼손 컵 파지, 오른손 병 파지, 붓기, 병·컵 내려놓기, 양손 열기·후퇴를 연결했다. 물체 부착이나 유체 순간이동, 실기체·카메라·ROS 접속은 없다.
- 105°·20초 조건 `final_record03` 1회에서 `task_pass: true`, `sequence_finished`, 종료 코드 0을 확인했다. 컵 잔류 648/918개(70.588%, 명목 41.472 mL), 밖으로 이탈 8개(0.871%, 명목 0.512 mL)다. 전체 조건에 대한 성공률은 아니다.
- 파지 유지, 실제 붓기 자세에서의 입자 이동, 입자 보존, 책상 지지·손 분리·그리퍼 열림·위치 안정화를 함께 검사한다. 최종 XY 오차는 컵 2.382 mm·병 1.625 mm였다. 139.7초 전체 녹화와 확대 구간을 Git 제외 로그 폴더에 보존했다.
- 컵 손목 반전, 컵 림·왼팔 상완 충돌, 급격한 관절 목표 변화, 양 부족을 순서대로 수정했다. 100°·4초는 18.4%, 100°·20초는 36.7%로 목표량 미달이었다. 실패 판정 기준을 낮추지 않고 경로·속도·붓기 각도를 수정했다.
- 왼손은 강체 패드, 오른손은 순정 평면 죠 프록시다. 랙 한 쌍만 내부 충돌에서 제외하고 블레이드 간격·실제 관절 범위를 확인한다. 손목–연결판 간격을 위한 추가 8 mm 장착은 별도 미보정 가설이며 원본 URDF·기본 설정은 보존했다. 접촉력은 정량 무게 검증이 아닌 접촉 신호로 사용한다.
- 실패 기록 `FAIL-20260921-0002/0003`과 근거 6개를 `~/robot-artifacts/pour_20260921/failures/`에 보존하고 SHA-256을 확인했다. 성공 IL 데이터로 편입하지 않는다.
- 검증: CPU 318 passed·2 skipped(기존 OpenCV ChArUco 제약), 구문·pyflakes·diff 검사 통과. 코드 리뷰에서 조기 물 이동, 중간 파지 유실, 잘못된 배치 위치, 후처리 예외의 거짓 성공 판정을 보강했다.
- 상세: [양팔 PBD 물붓기 시뮬레이션](docs/20260921_양팔_PBD_물붓기_시뮬레이션.md). 실물 물붓기·RGB 인식·TPU 변형·이동 베이스 검증은 포함하지 않는다.

## 2026-09-21 | 오른손 경로·충돌 형상 대조와 교체 조립 가설 시험

- 기존 모델에서 100/120 mm 후퇴와 convexHull/convexDecomposition 네 조합을 대조했다. 모두 비파지 링크 접촉으로 실패했다. 원본 STL 감사에서는 APPROACH 목표에서 모터 2,409개·follower 4,112개 정점이 병 원기둥 안쪽을 1 mm 넘게 침범했다. 경로 또는 볼록 근사만의 문제로 설명할 수 없으며 실물 조립 오류 확정과는 구분한다.
- 공식 ggao 렌더를 근거로 별도 `bottle_replacement_experiment.json`에 교체 조립 가설을 추가했다. 로그 사본에서 기존 집게 조립체를 충돌 가능한 명목 서보 박스로 교체하고 ggao 평면 죠·레일은 유지한다. 패드·홈·테이프·물체 부착은 없다. 원본 URDF와 기본 설정은 보존했고 장착 좌표·서보 치수는 미보정 가정이다.
- 가설 모델의 35 g·235 g 등가 강체 병은 파지→상승→같은 책상 내려놓기→손 분리를 통과했다. 최신 근거는 Git 제외 `logs/bottle_path_audit_20260921/provenance_35`·`provenance_235`다. 원본 모델 실패를 해결 완료로 바꾸거나 실물·액체 유동·물붓기 성공으로 표시하지 않는다.
- 실행 파일·입력 설정·유효 설정 해시와 CLI 변경을 함께 저장한다. `assembly_mode`, `model_calibrated=false`, `physical_grasp_verified=false`를 결과에 남긴다. 이전 실패와 성공 로그를 덮어쓰지 않았으며 실패 은행은 investigating·학습 편입 false를 유지한다.
- 공유 물리 코드의 왼손 5 g 컵·y=−5 mm 회귀는 `left_final`에서 복구 후 내려놓기까지 통과했다. 이후 변경은 설정 출처 기록뿐이다. 전체 CPU 시험 282 passed·2 skipped(기존 OpenCV 제약), pyflakes·diff 검사 통과. 실물 팔·카메라·ROS 접근과 영상 촬영은 하지 않았다.
- 별도 리뷰에서 최신 실행의 코드·모델·입력/유효 설정 해시와 성공 판정, 비파지 접촉 0 N을 대조했고 코드 수정 요청은 없었다. LSP 도구가 없어 compileall·flake8 검사로 보완했으며 형식 판정은 COMMENT다. 실패 은행 근거 29개 SHA-256 검증도 통과했다.

## 2026-09-21 | 순정 ggao 오른손 병 접촉 실행기와 장착 형상 간섭 확인

- 오른손은 순정 평면 죠이며 패드·홈·인서트·테이프를 넣지 않았다. 원본 URDF·보정 파일은 유지하고 로그 사본의 베이스·죠 충돌 박스를 기존 시각 박스에 맞췄다. 실측 STL 모델로 표시하지 않는다.
- 공통 컵 실행기에 오른팔 경로와 두 직선 죠의 m/N 제어를 추가했다. 병 중간 접근·닫힘·상승·복귀 IK 계획은 통과했지만 물리 파지는 실패 상태다. 시뮬레이션만 사용했으며 물붓기·영상 촬영·실물·카메라·ROS 접근은 없었다.
- 가정 병은 35 g·지름 60 mm·높이 200 mm·마찰 0.3이다. 최초 `empty01`은 닫기 전 수평 이동 3.045 mm로 실패했다. 비파지 링크 계측을 추가한 `empty02_contacts`는 `right_gripper_link` 약 1.700 N·두 죠 0 N을 6.433초에 확인했다. `empty03_verified`에서도 같은 비파지 접촉으로 종료했다. 세 실행 모두 닫기·상승을 수행하지 않았다.
- 기존 SO101 follower 형상과 ggao 장착 변환의 조합을 조사 중이다. 상류 README/파일만으로 기존 follower의 제거·유지를 확정하지 못했으므로 어느 쪽도 정답으로 단정하거나 충돌 형상을 삭제하지 않았다. 실제 오른손 장착 사진·위치 대조 후 모델을 보정해야 한다.
- 실패 `FAIL-20260921-0001`과 원본 근거 9개를 저장소 밖 `~/robot-artifacts/bottle_contact_20260921/failures/`에 보존했다. 스키마와 SHA-256을 검증했으며 원인은 가설 상태, BC 편입은 false다. 실험 로그는 Git 제외 `logs/bottle_contact_20260921/`에 있다.
- 공통 코드의 왼손 5 g 컵·y=−5 mm 회귀 시험은 복구 1회 후 내려놓기까지 통과했다. CPU 전체 265 passed·2 skipped(기존 OpenCV ChArUco 제약), 구문·pyflakes·diff 검사 통과다. 실행법·관측 결과·재개 조건을 README와 기존 Isaac 프리뷰 문서에 반영했다.
- 별도 코드 리뷰에서 필수 수정사항은 없었다. 최신 `empty03_verified`·`left_final`의 소스/설정 해시와 물리 tick, 녹화 프레임 0개를 확인했다. LSP 진단 도구가 없어 구문·pyflakes로 대체했으며 리뷰의 형식 판정은 COMMENT다. 실제 오른손 장착 형상 미확정은 여전히 남아 있다.

## 2026-09-21 | 왼팔 내려놓기 검증 인계·커밋 정리

- 9월 19일 실행한 `--place`의 상승→하강→책상 지지→열림→수평 후퇴→상방 이탈을 정리했다. 같은 책상으로 돌려놓는 강체 실험이며 선반 운반·실물 FinRay·물붓기는 아니다.
- 5/10/20 g 조건별 1회와 5 g·y=−5 mm 복구 결합 1회가 내려놓기까지 통과했다. 최신 `final_gui_verified`도 복구 1회·접지 이벤트·최종 PASS, 소스 4개 해시 일치·녹화 프레임 0개다. 근거는 Git 제외 `logs/cup_place_20260919/`에 있다.
- 최초 25 mm 후퇴 경로는 상방 이탈 중 재접촉으로 실패했다. 하강 종료·IK 경로를 고친 뒤에는 25/65 mm 모두 통과해 거리 단독 원인으로 확정하지 않았다. 실패 `FAIL-20260919-0001`은 저장소 밖 `~/robot-artifacts/cup_place_20260919/failures/`에 원본·가설·재시험으로 보존했고 스키마 1건 및 근거 11개 SHA-256 검증을 통과했다.
- 별도 리뷰에서 발견한 접지 이벤트 없이 성공하는 경로와 하강 중 파지 상실 뒤 낙하를 성공으로 처리하는 경로를 차단했다. 마지막 판정 수정 후 전체 251 passed·2 skipped(기존 OpenCV 제약), 관련 46 passed, 코드 리뷰 APPROVE다.
- 위치 제어는 힘 제어가 아니다. 10 g 시험의 지지 확인 마지막에 약 1.33 N이 남았으므로 얇은 컵의 변형·허용 힘 검증은 별도다. 원본 URDF·실기체·카메라·ROS는 변경/접속하지 않았다. README와 기존 실행 문서에 범위·실행법·한계를 반영했다.

## 2026-09-19 | 컵 위치 오차의 후퇴·장면 좌표 재관측·IK 재접근

- `simulate_cup_contact.py --recover`에 열린 손 후퇴→0.5초 관측→새 위치 IK→재접근을 추가했다. 실제 실행한 관절 이력을 역순으로 추종하고 기본 1회만 재시도한다. 실물 팔·카메라·ROS에 접속하지 않았고 원본 URDF/보정 파일을 유지했다.
- 관측은 시뮬레이터 정답 좌표이며 RGB 검출이 아니다. 컵의 초기 배치 후 pose 쓰기나 손과의 부착은 없다. 현재 관절값에서 재계획하고, 실패 이벤트·후퇴 경로·관측 위치·새 계획을 로그에 보존한다. 마지막 시도만 상승 판정에 사용해 이전 접촉이 새 성공 근거로 섞이지 않게 했다.
- 5 g·y=−5 mm 오차에서 같은 초기조건 3회 모두 접촉 감지→후퇴→재접근 후 약 60.18 mm 상승을 확인했다. x=−5/+5 mm, y=+5 mm, 오차 없음은 각 1회 복구 없이 통과했다. 동일 가정 강체 장면의 재현 시험이며 실물 성공률/카메라 허용 오차가 아니다.
- 후퇴 중 접촉력 최대 약 1.17 N을 관측했다. 역재생 후퇴가 무접촉 경로나 단조 접촉력 감소를 보장하지 않음을 명시했다. 변위·기울기·접촉력 초과, 접촉 미해제·관측 불안정·IK 거부·재시도 소진은 실패로 종료한다.
- 복구를 끈 최신 코드의 대조 시험은 같은 −5 mm 조건에서 `premature_cup_contact`로 종료했고 닫기·상승을 실행하지 않았다. 근거는 Git 제외 로컬 `logs/cup_recovery_20260919/`의 `minus5_fix`, `ym5_r2`, `ym5_r3`, `yp5`, `xm5`, `xp5`, `nominal`, `control_no_recovery`다.
- 최종 `final_gui` 실행도 재시도 1회 뒤 PASS였으며 창은 결과를 유지하도록 물리 진행을 멈췄다. 최신 세 도구 해시, 물리 tick 간격, 단조 증가 시간, 녹화 프레임 0개를 대조했다. 대조 시험 역시 같은 소스 해시로 확인했다.
- 실제 FinRay STL의 선정 해시와 외곽 `80.0×24.74545×24.087 mm`를 재확인했다. 장착 변환·출력물 질량/무게중심·TPU 특성·라이선스가 미확정이어서 실제 형상 반영은 보류했다. 사각 강체 패드 결과를 실제 FinRay 모델 검증으로 표시하지 않는다.
- 검증: 전체 CPU 시험 232 passed·2 skipped(기존 OpenCV 제약), 신규/관련 시험 27 passed, pyflakes·구문·diff 검사 통과. 재계획 시작 관절의 float32 JSON 저장 오류를 고치고 회귀 시험을 추가했으며, 과거 v1 설정의 recovery 누락만 기본값으로 보완하고 명시 오류는 거부한다. 최종 영상은 물 서빙 전체 완성 후이며 이번 시험은 녹화하지 않았다.

## 2026-09-19 | 왼손 컵 접촉 실험과 가벼운 컵의 파지 전 밀림 분류

- 빈손 손목 회전을 컵 파지 시연으로 안내했던 범위를 정정했다. 기존 프리뷰는 `Empty-hand check`로 표시하고, 별도 `simulate_cup_contact.py`에서 수평 접근→닫기→양측 접촉→상승을 실행한다. 실물 팔·카메라·ROS에는 접속하지 않았다.
- 원본 회전식 그리퍼 관절은 유지하고 로그 사본에 80 mm 강체 패드를 작성했다. FinRay STL·TPU 변형·실물 장착 보정은 아니다. 책상 높이 720 mm, 컵 x=390 mm·y=170 mm·지름 70 mm·높이 120 mm는 실험 가정이며 기존 프리뷰 위치에서 성공했다고 해석하지 않는다.
- 컵은 중력·충돌·마찰로 움직이며 손에 부착하거나 실행 중 위치를 덮어쓰지 않는다. 고정 TCP 좌표 프레임을 병합해 importer 기본 관성이 팔에 추가되는 문제를 제거했다. 렌더·캡처가 물리 시간을 추가 진행하지 않도록 분리했고 물리 tick 증가량을 검사한다.
- 가벼운 플라스틱 컵 피드백으로 기본 질량을 10 g으로 변경하고 고정측 접근 여유를 3 mm 늘렸다. 닫힘 전 접촉 또는 수평 이동 3 mm 초과는 실패로 기록해 닫기/상승을 계속하지 않는다. RGB 재인식·재계획 복구와 컵 찌그러짐은 미구현이다.
- 같은 가정 장면의 5·10·20 g 조건을 각 1회 실행했다. 닫힘 전 손가락 접촉력은 0 N, 수평 변화는 수치 오차 수준이었다. 최종 상승은 각각 60.18/60.11/60.00 mm, 접촉 중심과 컵 중심 거리는 약 3.3 mm였다. 단일 조건 실험이며 일반 성공률·실물 성능이 아니다.
- 5 g 컵 초기 위치에 y=−5 mm 오차를 주입하면 `ALIGN_MIDDLE`에서 `premature_cup_contact`로 실패했다. 그 시점 접촉력 약 0.877 N, 컵 수평 이동 약 0.026 mm였고 닫기·상승은 실행하지 않았다. 이미 크게 밀린 후가 아니라 최초 접촉 단계에서 분류한 결과다.
- 증거는 Git 제외 `logs/cup_contact_20260919/{light_5g_01,light_10g_01,light_20g_01,offset_5g_minus5mm,light_10g_final}/`다. 최종 GUI 실행은 소스 해시 일치·PASS를 확인했고 이들 경량 컵 시험은 녹화 프레임 0개다. 최종 영상은 양팔 물 서빙 전체가 완성된 뒤 촬영하기로 했다.
- 기존 프리뷰의 Reset/데모 재시작·중단·시간 종료·예외 때 녹화 결과가 누락되던 문제도 수정했다. 실행별 manifest에 완료 여부와 종료 사유를 기록한다.
- 검증: 전체 CPU 시험 219 passed·2 skipped(기존 OpenCV ChArUco API 제약), 구문·pyflakes·diff 검사 통과. 코드 리뷰에서 필수 URDF 요소 누락 검사와 실패 분류 경계 시험을 보강했다. IL 데이터는 이 IK 실험에 사용하지 않았으며 로그를 실물 ACT 성공 시연으로 편입하지 않는다.

## 2026-09-18 | 컵 중간 수평 측면 파지 재설계와 양팔 후보 검토

- 사용자 관찰로 초기 Isaac 프리뷰의 컵 관통·비스듬한 접근 문제를 확인했다. 자동 재생을 기본에서 끄고 컵 높이 50%·수평 접근·죠 가로 기준축 수평을 조건으로 하는 비동작 양팔 IK 후보 도구를 추가했다.
- 왼손은 현행 명목 tool0 모델에서 중간점 위치 오차 약 5.77 mm·수평 오차 약 7.22°로 조건을 충족하지 못했다. 오른손은 `right_tool0` 기준 수평 IK 3개 후보가 나왔지만 병 주변 접근 2개는 외곽 겹침 검사에서 거부됐다. 국소 탐색 실패를 기구학적 불가능이나 실물 실패로 단정하지 않는다.
- 물체 원기둥·책상 판·반대 팔에 대해 URDF collision 외곽 검사와 팔 관절 한계 검사를 추가했다. 보수적 검사로 오탐이 가능하며 자가충돌·로봇 구조물·TPU 접촉/변형·연속 경로 검증은 아니다. 실패 후보는 화면에서 마지막 통과 자세를 유지한다.
- 실제 Isaac GUI에서 6개 후보를 검토해 오른손 reorient 1개만 적용하고 나머지 5개가 HOLD되는 것을 manifest로 확인했다. 적용 자세의 시뮬레이터 값 차이는 좌 4.64e-8 rad·우 5.00e-8 rad였으며 양팔 구동 추종 성능을 뜻하지 않는다. 장면 재개방도 통과했다. 로컬 증거: `logs/isaac_workcell_20260918/body_side_v2/`.
- 검증: 전체 pytest 191 passed·2 skipped(기존 OpenCV ChArUco 제약), 구문·diff 검사 통과. 원본 URDF·캘리브레이션·서보 실행기는 유지했고 실물 접속은 없었다. 닫기·들어올림은 미구현/미검증 상태로 남긴다.
- 상세와 재실행: [컵 중간·양팔 측면 파지 재설계](docs/20260918_컵중간_양팔_측면파지_재설계.md). README와 프리뷰 안내도 초기 갤러리와 현행 후보 검토를 구분했다.

## 2026-09-18 | Isaac Sim 5.1 전체 모델·작업 환경 프리뷰

- 실물·카메라·ROS 접속 없이 로봇 전체와 가정 치수의 책상·컵·병을 Isaac Sim 5.1 GUI에 표시했다. 계획 자세 2개와 저장 자세 2개를 캡처하고 저장 USD 재개방까지 확인했다.
- 원본 URDF의 구형 바퀴 간격 320 mm와 앞뒤 중앙 캐스터 배치를 발견했다. 팔 FK와 원본 파일은 보존하고 프리뷰 사본에만 migration 기록의 간격 510 mm·바퀴 반경 32.9 mm·후방 캐스터 2개 프록시를 적용했다. 캐스터 장착 중심은 추정이며 주행 좌표계 통합·관성 재계산은 하지 않았다.
- 베이스 고정·중력/접촉 제외 상태의 자세 갤러리다. 보간은 실제 기록 궤적이 아니며 관절 한계·충돌 안전·동역학·파지 성공은 미검증이다. 왼손 FinRay와 RGB 3대는 아직 모델에 반영되지 않아 GUI·manifest·문서에 차이를 표시했다.
- 검증: 전체 pytest 170 passed·2 skipped(기존 OpenCV ChArUco API 제약), 신규 시험 17개 전부 통과. 별도 코드 리뷰 차단 결함 없음, Python 구문·diff 검사 통과. 실행 증거는 Git 제외 `logs/isaac_workcell_20260918/gui_final/`에 있다.
- 실행법·검증 범위: [URDF 작업 환경 프리뷰](docs/20260918_URDF_Isaac51_작업환경_프리뷰.md). README도 갱신했고 활성 URDF·캘리브레이션·서보 실행기는 변경하지 않았다.

## 2026-09-18 | 컵 파지 오프라인 재생·TCP 가정 비교·시간 동기 경로

- 실물·카메라·서보에 접속하지 않고 저장된 9월 17일 자료로 재검토했다. TCP 오차 단일 원인 확정을 철회하고 컵 좌표 기준·재배치·모델 TCP·관절 추종을 분리했다. README와 인계 문서를 함께 정정했다.
- `replay_cup_pick.py`로 원본 JSON·사진·FK용 URDF를 Git 제외 로그 폴더에 보존하고 해시 manifest·HTML을 생성했다. pregrasp 저장 자세는 계획 대비 최대 2.7257°/명목 TCP 16.02 mm 차이였고, 이후 재배치 시점 자세는 37.9785°/150.14 mm 차이였다. 후자는 도달 오차가 아니며 두 수치 모두 실물 컵 위치 오차가 아니다.
- FinRay 선정 STL 해시와 외곽 `80.0×24.74545×24.087 mm`를 확인했다. 새 `preview_finray_tcp.py`는 별도 URDF에 물리 형상이 없는 가정 프레임만 추가한다. 실측 장착 변환·접촉 중심·질량과 라이선스 확인 전이므로 활성 URDF·collision·inertial은 유지했다.
- `prepare_pick_execution.py`의 5축 길이·유한 숫자·계획/감사 대응 검증을 보강했다. `build_pick_schedule.py`는 공통 시간 진행률로 감사 시작→pregrasp→grasp를 보존한다. 저장 자료 예시는 52개 샘플·5.068205초이며 `start_recovery_only`, `collision_free=false`다. 실물 실행기에 연결하거나 시간 추종을 검증한 것은 아니다.
- 절차·명령·남은 실측은 [오프라인 검증과 재개 조건](docs/20260918_컵파지_오프라인검증과_재개조건.md)에 있다. 활성 캘리브레이션·서보 실행기 변경과 원격 push는 수행하지 않았다.
- 검증: `python3 -m pytest -q tools tests -rs`에서 153 passed·2 skipped. 두 skip은 현 시스템 OpenCV의 ChArUco 보드 생성 API 미지원 때문이며 신규 시험은 생략하지 않았다. 저장 자료 기반 세 도구 CLI, Python 컴파일, diff 공백 검사도 통과했다.
## 2026-09-21 | PR #42 CI Xacro 의존성 오류 수정

- GitHub PR gate의 `test_calculation_and_isaac_static_contract_pass` 실패를 확인했다. CI와 같은 pip Xacro 2.1.1 환경에서 `ament_index_python` 누락을 재현했다.
- 패키지 내부 Xacro include 6개를 파일 기준 상대경로로 변경했다. ROS 패키지 검색을 차단하고 임시 작업 디렉터리에서 확장해 기존 URDF와 비교하는 회귀 테스트를 추가했다.
- Python 3.12에서 테스트 69개 PASS. Markdown 로컬 링크 85개 파일, README 자동 요약, Python 구문, URDF·Xacro 계약과 저장된 URDF 일치 검사를 통과했다.
- 실물 로봇 명령은 실행하지 않았다. PR 브랜치 반영 후 GitHub 검사 결과는 해당 PR에서 확인한다.

## 2026-09-17 | 왼손 FinRay 실물 컵 접근 실패와 재캘리브레이션

> 2026-09-18 정정: 아래 당시 기록의 TCP 원인 확정·단일 좌표 실측 기준·모든 실행의 position-only
> 표현은 검증 범위를 넘었다. 상단 카메라 경로 `2.1`은 허브 하위이고 왼손목 `4`가 노트북 포트다.
> 부하·온도 제외는 사용자 지시 이후 해당 옵션을 붙인 실행에만 적용된다. 초기 팔 실행은
> 부하·온도를 판독했다. 현행 판단은 [오프라인 재검토](docs/20260918_컵파지_오프라인검증과_재개조건.md)를 따른다.

- 상단 RGB는 노트북 직결 경로 `pci-0000:65:00.3-usb-0:2.1`, 왼손목 RGB는 직결 경로 `pci-0000:65:00.3-usb-0:4`에서 각각 640×480 스트림을 확인했다. 대시보드 기본 손목카메라 경로도 직결 포트로 바꿨다.
- 투명컵을 왼팔 작업영역에 다시 놓은 뒤 `base_footprint=(0.320, 0.170) m`, 아래로 55도 접근 계획으로 pre-grasp와 grasp 관절 목표까지 실물을 이동했다. 작은 2도 실물 waypoint는 P게인 16의 정지 오차보다 작아 반복 정지했으므로, 충돌 감사 간격은 2도로 유지하고 실물 waypoint는 최대 180 tick, 도달 허용치는 40 tick으로 사용했다.
- 그리퍼를 순정 범위 `1409~2784`로 제어한 것은 교체된 80 mm FinRay 기준과 맞지 않아 ID 6만 다시 기록했다. 손으로 확인한 원시 끝점은 `1414~2871`, 양 끝 40 tick 여유를 둔 저장 범위는 `1454~2831`, drive mode는 0이다. 기존 JSON은 로컬 백업으로 남겼고 새 값은 `calibration/bi_follower/arms_left.json`에 반영했다.
- 사용자 지시에 따라 이번 실물 실행은 `--position-only`로 부하·온도를 읽거나 정지 조건에 쓰지 않았다. 위치 발산과 0.5초 스톨만 유지했으며, 연속 단계 성공 시 팔·그리퍼 토크를 유지할 수 있게 했다. 위치 스톨만으로 물체 접촉을 판정하지 않으며 스톨은 계속 실패·토크 해제로 처리한다.
- 최종적으로 팔은 계산된 grasp 자세에 도달했고 그리퍼도 새 닫힘 한계 근처 raw 1464까지 움직였지만, 상단 영상에서 컵이 두 손가락 중심에 들어가지 않았고 그리퍼가 끝점까지 닫혔다. 따라서 **컵 파지는 실패**다. 원인은 새 FinRay의 실제 TCP·유효 파지 중심과 URDF `left_cup_tcp`, 그리고 실측 300 mm 단일 좌표 사이의 정렬 오차로 분류한다. 다음 실행은 같은 좌표를 반복하지 말고 열린 손가락 중심의 영상 좌표 또는 실측 TCP 오프셋을 먼저 보정한다.
- 종료 시 ID 1~6 토크를 모두 0으로 확인했다. 컵을 들어 올리거나 운반하지 않았다.

## 2026-09-17 | 실측 300 mm 컵의 기울임 접근 IK와 연속 경로 감사

> 2026-09-18 정정: 300 mm의 원점·축과 컵 재배치 후 위치는 확정되지 않았다. 아래 오차는
> 모델 내부 IK 잔차이며 실물 정확도가 아니다. 초기 충돌 쌍 수 감소만 확인했으며 관통 깊이의
> 단조 감소·실물 안전은 검증하지 않았다. 쌍별 최소 거리 `null`은 간섭 없음의 근거가 아니다.

- 상단 RGB 최신 프레임에서 사용자가 바꾼 투명컵을 COCO `cup` confidence 0.815로 검출했다. 사용자가 잰 왼팔 장착축 기준 전방 300 mm·좌우 0 mm를 `base_footprint`의 `(0.320, 0.170) m`로 변환했다.
- 완전 수평 접근은 낮은 컵 몸통에서 손목 한계에 걸렸지만, 공구축을 아래로 55도 기울이면 책상 위 70 mm 파지 중심에서 pre-grasp 오차 0.14 mm·최소 관절 여유 46.07도, grasp 오차 0.17 mm·여유 67.15도의 해를 얻었다.
- 현재 처진 자세 `[-0.44, -96.31, 95.82, 71.08, -77.58]°`에서 pre-grasp·grasp까지 2도 간격 52개 샘플을 감사했다. 초기 4개 샘플은 이미 존재하던 상판 접촉·자가접촉만 단조롭게 줄었고 새 충돌은 없었다. sample 4부터 grasp 끝까지 충돌 0이며, 첫 안전 자세는 `[-0.40, -89.05, 89.23, 68.81, -69.63]°`다.
- 결론: 별도 복귀 후 토크 해제가 아니라 현재 자세→충돌 탈출→pre-grasp→grasp를 한 제어 세션으로 실행한다. 이번 단계에서는 검출·IK·충돌 감사만 수행했고 실물 컵 접근·그리퍼 개폐는 실행하지 않았다.

## 2026-09-17 | 왼팔 실물 복귀 실행과 토크 해제 처짐 확인

- 승인받은 왼팔 복귀만 실행했고 컵 접근은 실행하지 않았다. 첫 시도에서 ID 검증이 없던 지연 응답을 손목 온도 85도로 오인해 즉시 중단했으며 실제 재판독 온도는 35도였다. STS status packet에 요청 ID·길이·오류 바이트·체크섬 검증을 추가하고 고온값은 연속 읽기로 확인하도록 수정했다.
- 2도 소프트웨어 목표 분할은 P게인 16과 정지마찰 때문에 팔꿈치·손목이 작은 오차에서 멈췄다. 충돌 감사는 2도 샘플을 유지하되 실물에는 검증된 최종 목표를 한 번 주고 STS3215 내부 속도 제한으로 이동시키는 방식으로 바꿨다.
- 단일 저속 목표에서 모든 관절이 올바른 방향으로 이동했고 부하 상한·온도·역방향·스톨은 발생하지 않았다. 기존 1.5초 고정 시간은 팔꿈치 이동에 짧아 단일 서보 도구와 같은 최소 8초 동적 예산으로 수정했다.
- 토크가 켜진 순간에는 목표 근처까지 도달했지만 안전 중단·토크 해제 뒤 어깨와 팔꿈치가 중력 방향으로 약 60 tick 처졌다. 최종 재판독은 5축 토크 OFF, 33~36도, hard limit 안이지만 충돌 모델상 낮은 접힌 자세가 유지됐다.
- 결론: 독립 복귀 후 토크 해제로는 안전 시작 자세를 유지할 수 없다. 실행기는 토크 해제 후 처짐을 완료 실패로 기록하며, 다음 실물 동작에서는 복귀를 컵 접근 궤적의 첫 구간으로 합쳐 한 제어 세션에서 토크를 유지해야 한다. 컵 좌표와 전체 경로가 없는 상태에서 복귀만 반복하지 않는다.

## 2026-09-17 | 왼팔 시작 충돌의 단조 탈출 경로와 동기 복귀 실행기

- LeRobot 0.4의 `MotorNormMode.DEGREES` 구현과 현재 환산식을 대조해 `(raw-mid)×360/4095`가 동일함을 확인했다. 좌표 변환 오류나 URDF 한계 임의 확장으로 처리하지 않는다.
- 현재 자세에서 어깨·팔꿈치만 한계 안으로 넣는 첫 후보는 상판 접촉과 자가충돌이 남아 폐기했다. 5개 관절을 URDF 중립 방향으로 함께 2도씩 보간하면 초기 6개 충돌 쌍이 새 충돌 없이 단조롭게 감소하고 sample 5에서 충돌이 모두 해소됐다.
- 관절 한계 여유 5도까지 포함한 첫 승인 후보는 sample 8의 `[-0.376, -93.643, 82.863, 69.829, -75.989]°`다. 최대 단일 관절 이동은 15.939도, 끝점 최소 한계 여유는 6.357도다.
- `audit_pick_trajectory.py`에 기존 접촉의 부분집합 유지, 충돌 쌍 수 비증가, 관절 한계 여유 단조 증가, 안전 상태 이후 재진입 금지를 검사하는 `start_recovery` 판정을 추가했다. `plan_safe_recovery.py`는 이 조건을 만족하는 첫 자세만 승인 전 미리보기 JSON으로 만든다.
- `execute_safe_recovery.py`는 계획 생성 뒤 자세 drift, 시작 토크, 전체 이동량을 먼저 차단하고 5축을 최대 23 tick(약 2도)씩 동기 waypoint로 보낸다. 부하·온도·0.5초 스톨을 감시하고 성공·실패 모두 목표를 현재 위치로 덮어쓴 뒤 토크를 풀고 기존 속도·가속도를 복원한다.
- 실제 포트 dry-run에서 현재 raw `[2040, 783, 2516, 2956, 1036]`, 목표 `[2041, 964, 2356, 2821, 1183]`, 8 waypoint를 재확인했다. 모의 버스 실행은 최종 목표 도달·토크 해제까지 PASS했다. 실물 이동은 건별 승인 전이라 실행하지 않았다.

## 2026-09-17 | 컵 파지 경로 충돌 감사와 현재 왼팔 시작 자세 판독

- 기존 `audit_urdf_clearance.py`의 폐기된 카메라 마스트 링크명 때문에 발생하던 `KeyError`를 수정하고, 링크당 첫 collision만 읽던 문제를 모든 collision 형상 결합으로 고쳤다. zero·transport·pour 기존 감사가 다시 실행되고 모두 PASS했다.
- IK 계획의 시작→pre-grasp→grasp를 최대 2도 간격으로 보간해 관절 한계, 좌우 팔, 왼팔 비인접 링크, 상판·카메라·LiDAR 구조물 충돌을 검사하는 읽기 전용 경로 감사 도구를 추가했다.
- 현재 왼팔 엔코더를 읽기 전용으로 재확인했다. 토크는 5축 모두 꺼져 있고 전압 12.1~12.2 V, 온도 34~36°C다. LeRobot degrees 환산 결과는 `[-0.44, -109.58, 96.97, 81.71, -88.92]°`다.
- 현행 URDF와 비교하면 shoulder_lift가 하한보다 9.58도 낮고 elbow_flex가 상한보다 0.14도 높다. elbow 원시 위치도 보정 상한보다 6 tick 높다. 좌표 규약 또는 URDF 한계를 실물과 대조하기 전에는 이 자세에서 실행 경로를 승인하지 않는다.
- 핀 고정한 TheRobotStudio `so101_new_calib.urdf`와 JD-AMR 실기 제어 코드도 shoulder_lift `±100°`, elbow_flex `±96.83°`를 사용한다. 현재 한계를 임의로 넓히지 않고, 실물 팔이 수동으로 캘리브레이션 끝단에 놓인 시작 자세 문제로 취급한다.
- 실물 팔에는 이동·토크·EEPROM 쓰기 명령을 보내지 않았다. 현재 상태 JSON은 시점 의존 산출물이라 `/tmp/holdflow_left_current_joint_state.json`에만 두고 저장소에는 커밋하지 않는다.

## 2026-09-17 | 상단 RGB 투명 컵 검출과 왼팔 자코비안 IK 드라이런 연결

- 상단 RGB 최신 프레임에서 YOLO11n COCO `cup` 검출을 확인했다. 투명 컵 confidence는 0.812였고, 검출 상자의 바닥 중심을 작업대 평면 접점으로 사용한다.
- 실측 대응점 네 개 이상을 클릭해 `base_footprint` 작업대 XY homography를 만드는 `workspace_plane_calibration.py`와, 검출 결과를 `left_cup_tcp` pre-grasp·grasp DLS IK로 연결하는 `cup_pick_dry_run.py`를 추가했다. 두 도구 모두 팔 명령을 보내지 않는다.
- 기존 수치 IK에서 `target-current` residual Jacobian에 갱신 부호가 반대로 적용된 결함과, 공구축이 정반대여도 같은 방향으로 판정되던 축 오차 결함을 수정했다. FK로 만든 도달 가능 목표를 1 mm 이내로 복원하는 회귀시험을 추가했다.
- 컵 접근은 손목 한계에 붙는 수직 top-down 대신 왼팔 베이스에서 컵 몸통으로 향하는 수평 접근으로 정했다. IK 결과가 5 mm를 넘거나 관절 한계 여유가 5도 미만이면 다음 충돌 검토 단계로 넘기지 않는다.
- 검증: 신규 pytest 9개와 ChArUco unittest 2개 통과, URDF 58링크·57관절 정적 검사와 품질 감사 PASS. 실측 작업대 평면 보정값이 아직 없어 실제 컵 좌표와 관절 목표는 생성하지 않았고 실물 팔도 움직이지 않았다.
- 현재 상단 RGB는 대시보드에서 online이며 왼손목 RGB는 USB 장치가 보이지 않아 offline이다.
## 2026-09-17 | ggao50 홈·교체형 인서트 폐기

- 오른손 ggao50은 순정 평면 죠를 무가공 상태로 사용하고 V홈·사다리꼴·평면 교체형 인서트는 현행 구성에서 제외했다.
- `prepare_ggao50_print.py`에서 STEP 다운로드와 인서트 볼트 구멍 가공을 제거했다. 현행 도구는 상류 STL을 그대로 방향 조정·슬라이싱한다.
- URDF에서 인서트 visual을 제거하고 순정 평면 죠 충돌 프록시로 갱신했다. 과거 인서트 생성기·메시는 의사결정 이력으로만 보존한다.
- 실물 물병 파지·미끄럼·회전은 아직 검증하지 않았으며, 이번 변경에서 팔을 움직이지 않았다.

## 2026-09-16 | 하단 차체 추가 적재 5 kg 예비 주행·RGB-D 연결 경로 확정

- 현재 하단 차체에 5 kg을 추가 적재하고 웹 수동 조종기로 실내 평지 주행을 수행했다. 사용자 관찰상 주행이 완료됐고 눈에 띄는 속도 저하는 없었다.
- 차체 자체 질량·총질량·명령 속도·시간·거리·전류·온도·전압 강하는 계측하지 않았으므로 `preliminary_pass`로만 기록한다. 정격 적재량이나 연속 운전 검증으로 확대하지 않는다.
- 실차 기준은 바퀴 반경 0.0329 m, 기하 중심거리 0.510 m, 프레임 340×450 mm, 바퀴 포함 폭 540 mm다. 과거 0.320 m 명목 설계값은 현재 조립 실차 주행 시작값으로 사용하지 않는다.
- Orbbec Astra S 단독 POC는 개발 노트북 USB에 직접 연결한다. 차체 이동 시험에서는 Pi 4B USB-A에 연결해 Pi가 드라이버·시각·ROS 토픽을 맡고, 노트북이 기록·RTAB-Map·3D 지도 생성·분석을 맡는다. 모터 제어보드나 LiDAR UART에는 연결하지 않는다.
- 파이 실측 토폴로지는 베이스 제어보드 `/dev/ttyS0` 헤더 UART, G4 LiDAR `/dev/ttyUSB0` CP210x 12 Mbps다. 외부 USB 장치는 G4 한 개만 열거돼 USB-A 4개 중 1개를 사용하고 3개가 남아 있다.
- 기계 판독값과 주장 한계는 `config/navigation/jdamr_migration.json`, 상세 절차는 [SLAM 실기체 이식](docs/20260912_JDAMR_SLAM_실기체이식.md)에 반영했다.

## 2026-09-14 | 바퀴 모터 이식·기본 주행을 SLAM 선행 게이트로 확정

- 사용자 확정 순서를 `같은 모델의 다른 바퀴 모터 이식 → SLAM 없는 기본 주행 → SLAM → LiDAR·RGB-D 역할 분담`으로 변경했다. 기존 RGB-D 단독 Visual SLAM 우선안은 기본 주행 게이트 뒤로 이동했다.
- 모터 ID·좌우 회전 부호를 다시 읽고 비접지 단독 바퀴, watchdog·정지, 저속 직진·후진·좌우 제자리 회전, odom 부호와 바퀴 파라미터를 순서대로 확인한다.
- G-DRIVE는 ID/부호 확정, 모든 정지 시험 PASS, 명령·차체·odom 부호 불일치 0건, 체결·배선·휠 간섭·예상 밖 접촉 0건을 요구한다. 접지 시험 전에 정지 반응시간·거리의 안전 상한과 시험 공간을 고정하고, 실측 뒤 거리·각도 반복 오차와 보정 허용치를 고정해 재시험한다. 미확정이면 다음 게이트로 넘어가지 않는다.
- 이번 변경은 실행 순서와 판정만 갱신했다. 모터 장착·베이스 구동·센서 실행·SLAM·팔 이동은 수행하지 않았다.

## 2026-09-13 | 시뮬레이션·검증 직무 경로와 Mimic·AMMR 고도화 기록

- 시뮬레이터 개수를 늘리기보다 실제 센서 데이터→환경 구성→폐루프 시험→실물 기록과 차이 분석을 강화한다. AMR/로봇 SW와 함께 시뮬레이션·검증을 지원 경로로 기록했다.
- 사용자 확인에 따라 `so101-pick-rl` 원격 `743b2ec`의 최신 인계·원본 평가 JSON을 조회했다. SO101-PickPlace-v0 1,024환경 PPO 300 iteration, 학습 seed 0·평가 seed 3개 각 200회, 전체 성공 0/600을 확인했다. 현재 Windows 프로세스 상태는 미확인이다.
- 실패 525회는 유효하게 든 뒤 목표 배치 미달이며 XY 접근/Z 하강/접촉 상실을 구분할 계측이 다음 작업이다. 이 호스트의 Mimic 이미지 생성(1환경, 성공 500개 목표)과 별도 PPO를 동일시하지 않는다. PPO의 39차원 입력 계약을 로컬 미커밋 45차원 계약과도 구분했다.
- 고도화 제안은 생성 데이터 QC·독립 정책 평가·센서/행동 계약 확인·정차 오차를 반영한 파지·실물 제한 검증이다. AMMR은 별도 새 프로젝트보다 현행 물 서빙의 이동→정지→조작→수납→이동 통합으로 다룬다.
- 당시 RGB-D P0/P1 우선순위는 유지한다고 기록했으나, 2026-09-14 결정으로 번호와 순서를 대체했다. 현재 P0/P1은 모터 이식·기본 주행이고 RGB-D/LiDAR 검증은 P2/P3이다. 이 항목에서 실행 중인 생성·학습은 중단하거나 변경하지 않았다.
- 상세 근거·평가 분기·다음 세션 인계: [매니퓰레이션과 AMMR 고도화](docs/20260913_시뮬레이션_매니퓰레이션_AMMR_고도화.md).

## 2026-09-13 | 당시 결정: 임시 장착 RGB-D 단독 검증 → LiDAR 통합

> 2026-09-14에 순서가 변경됐다. 아래 센서 검증 범위는 보존하되 현행 첫 작업은 모터 이식과 기본 주행이며, 현행 단계 번호는 P2/P3이다.

- 당시 사용자 우선순위는 새 양팔 차체 완성 전 RGB-D 단독 Visual SLAM을 먼저 검증하는 것이었다. 2026-09-14 결정으로 모터 이식·기본 주행 뒤로 이동했다.
- 당시 첫 작업으로 정한 카메라 모델·드라이버·RGB/Depth/CameraInfo·정렬·시간축·장착 좌표 확인과 기록 재생은 현행 P2에서 수행한다. LiDAR 주행 코드를 교체하거나 두 SLAM이 같은 TF를 발행하도록 하지 않는 경계는 유지한다.
- 다음 세션의 입력·기록 항목·완료 기준·실패 평가·실물 실행 경계는 [전용 인계 문서](docs/20260913_RGBD_SLAM_우선순위와_다음세션.md)에 고정했다.
- 당시 P0/P1이라고 부른 RGB-D/LiDAR 검증은 현행 P2/P3이다. 이후 RGB-D·IK 조작 반복성과 동일 과제 ACT 평가를 우선하고 SLAM 백엔드 추가·새 RL 확장을 후순위로 두는 판단은 유지한다.
- 사용자 추가 확인: 모터는 같은 모델인 다른 차체의 개체이며 ID는 미확정. 기존 제어보드·Pi·G4 LiDAR를 유지하고 LiDAR 높이·위치는 바뀔 수 있다. 장착 완료·실측·실행 승인을 뜻하지 않는다.
- 독립 리뷰 지적에 따라 이식 계약 schema v2에서 모터·보드 재사용 결합 필드를 분리했다. 확인된 부품 계획과 미확정 ID·실장·실측을 구분하고 실물 구동 비활성을 고정하는 회귀 테스트를 추가했다.
- 이번 변경은 우선순위와 기록만 반영한다. 센서 실행·차체 주행·팔 이동·정책 학습·사이트 배포는 수행하지 않는다.

## 2026-09-12 | JD-AMR SLAM 실기체 이식 기준선 고정

- 작업 브랜치: `feat/jdamr-base-migration`
- JD-AMR `8204ffde34985fa7984fe4e6093801ff3897432c`의 커밋 파일만 내보내는 도구와 파일별 SHA-256 manifest를 추가했다.
- 원본 742개 파일을 별도 로컬 작업공간에 내보내고 해시를 대조했다. dirty/untracked 제외와 덮어쓰기 거부 테스트 PASS.
- 현행 320 mm 기하 트레드와 기존 183.6 mm 유효값, G4 실행 코드와 LDS-03 설계 차이를 이식 계약에 기록했다.
- 당시에는 모터·제어보드 재사용안이었으나, 2026-09-13 사용자 확인으로 모터는 같은 모델의 다른 차체 개체, 제어보드·Pi만 기존 장치를 유지하는 것으로 정정됐다. 실장·측정·주행 검증 전이라는 경계는 유지한다.
- 절차: [SLAM 실기체 이식](docs/20260912_JDAMR_SLAM_실기체이식.md)

## 2026-09-10 | 450×340 mm 상부 프레임·4분할 상판·JDAMR 구동계 재사용

**결론**: 300×300 mm 한 장 상판안을 폐기하고 하부와 같은 450×340 mm 상부 프레임,
2020 기둥 4개, 프로파일 지지형 PETG 4분할 상판으로 CAD·URDF를 전환했다. SO-101 중심은
전면에서 150 mm, 450 mm 폭의 좌우 끝 y=±170 mm이며 카메라 광학 중심은 기존 z=970 mm다.

**구현**
- 4분할 상판, 배터리·LDS-03 출력 장착판, 상·하부 둘레와 분할선 보강 레일 STEP/STL·URDF
- 현행 URDF 실제 축척 조립·상면 이미지와 모델 문서
- 당시 JDAMR STS3215-C018 두 개 재사용안은 ID 2=왼쪽, ID 1=오른쪽이었다. 2026-09-13에 같은 모델의 다른 모터를 사용하기로 바뀌어 이 ID 배정은 폐기했고, 반경 0.0329 m와 중심거리 0.320 m만 보정 시작값으로 남겼다.
- Raspberry Pi 5는 후순위로 기록하고, 도입 시 Nav2·센서·베이스·안전을 온보드로,
  ACT·고부하 비전은 무선 노트북 GPU에 유지

**명목 무게**
- 빈 로봇 7.379 kg, 컵 0.30 kg+물통 0.56 kg 시 8.239 kg,
  물통 1.10 kg 시 8.779 kg
- 0자세 COM `(21.4, -3.2, 496.0) mm`, 정적 지지 여유 76.9 mm
- 토크 1차 계산상 저속 평지 주행 후보이나 동적 전도·스톨 전류·발열·미끄럼 실측 전

**실물 실행 경계**: 이번 변경에서는 팔과 베이스를 움직이지 않았다. 기존 JDAMR의
`wheel_separation=0.1836`은 새 차체에 재사용하지 않으며 0.320 m에서 실주행 보정해야 한다.

## 2026-09-10 | 양팔(bi_so_follower/bi_so_leader) 텔레옵 구성, 왼팔 캘리브레이션 확보, 사용법 문서 반영

**결론**: 왼팔(리더 COM5·팔로워 COM15) 서보 EEPROM 에 이미 유효한 캘리브레이션 범위가 있는
것을 읽기 전용으로 확인하고 lerobot JSON 으로 내보내, 오른팔(이 문서 상단 세션에서 완료)과
합쳐 `bi_so_follower`/`bi_so_leader` 로 한 프로세스에서 양팔 동시 텔레옵을 확인했다.
`bi_so_follower.py` 가 좌우 `gripper_protection` 을 안 읽는 문제를 patch 로 추가 보강했다.
`docs/20260910_텔레옵_IL_사용법.md` 에 양팔 텔레옵·녹화·학습·자율실행 절차를 반영했다.

**구현**
- `calibration/so_follower_left/follower_left.json`, `calibration/so_leader_left/leader_left.json` — 왼팔 EEPROM 을 `export_lerobot_calibration.py` 로 그대로 내보냄 (서보 미동작)
- `calibration/bi_follower/{arms_left,arms_right}.json`, `calibration/bi_leader/{arms_left,arms_right}.json` — `bi_so_follower`/`bi_so_leader` 가 기대하는 `<id>_left.json`/`<id>_right.json` 이름 규칙으로 좌우 개별 파일 조립
- `tools/servo/bi_so_follower_gripper_protection.patch` — `bi_so_follower.py` 가 `left_arm_config`/`right_arm_config` 의 `gripper_protection` 을 안 읽고 항상 `false` 로 무시하던 문제 패치
- `docs/20260910_텔레옵_IL_사용법.md` — 3-1절(양팔 동시 텔레옵), 5절 양팔 녹화, 6·7절 양팔 비고, 10절 관련 파일 추가

**검증**
- 왼팔 `servo_check_calibration.py`: JSON=EEPROM 일치, `0~4095 오염`·`폭 작음` 없음 (elbow_flex 가 현재 자세에서 기록 범위를 5~7틱 벗어남 — 오차 수준, ok 판정에 영향 없음)
- `bi_so_follower_gripper_protection.patch`: `git apply --check` 통과 (아직 사용자가 실제 적용은 안 함)
- 양팔 동시 텔레옵(`bi_so_follower`/`bi_so_leader`, COM15/COM16 팔로워, COM5/COM14 리더) 사용자 확인 — 정상 동작

**배운 것**
- 이 하드웨어는 왼팔도 이미 물리적으로 캘리브레이션돼 있었다 — JSON export 만 누락된 상태였다. 재캘리브레이션 전에 `servo_read.py`/`export_lerobot_calibration.py` 로 EEPROM 부터 확인하면 4절 전체를 다시 안 해도 될 수 있다
- 왼팔은 스톡 회전 죠라 `gripper_protection=true` 가 필요하고 오른팔(ggao50)은 `false` 가 필요하다 — 좌우가 반대
- `bi_so_follower`/`bi_so_leader` 의 캘리브레이션 파일명은 `{calibration_dir}/{robot.id}_{left,right}.json` 규칙이라 단일팔 캘리브레이션 파일을 그대로 못 쓰고 이름을 맞춰 복사해야 한다
- 팀 로컬 patch(`lerobot_gripper_protection.patch`)는 `so_follower.py` 만 고쳐서 `bi_so_follower.py` 경로에는 반영이 안 된다 — 양팔 확장 시 패치 커버리지를 따로 확인해야 한다

**남은 일**: `bi_so_follower_gripper_protection.patch` 실제 적용·재검증(과부하 없이 왼팔 그리퍼가
쥐는지), 외부 카메라 2~3대(정면 공용 + 좌우 손목) 경로 확정 후 양팔 첫 녹화, 이 세션 변경분
커밋·푸시

---
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

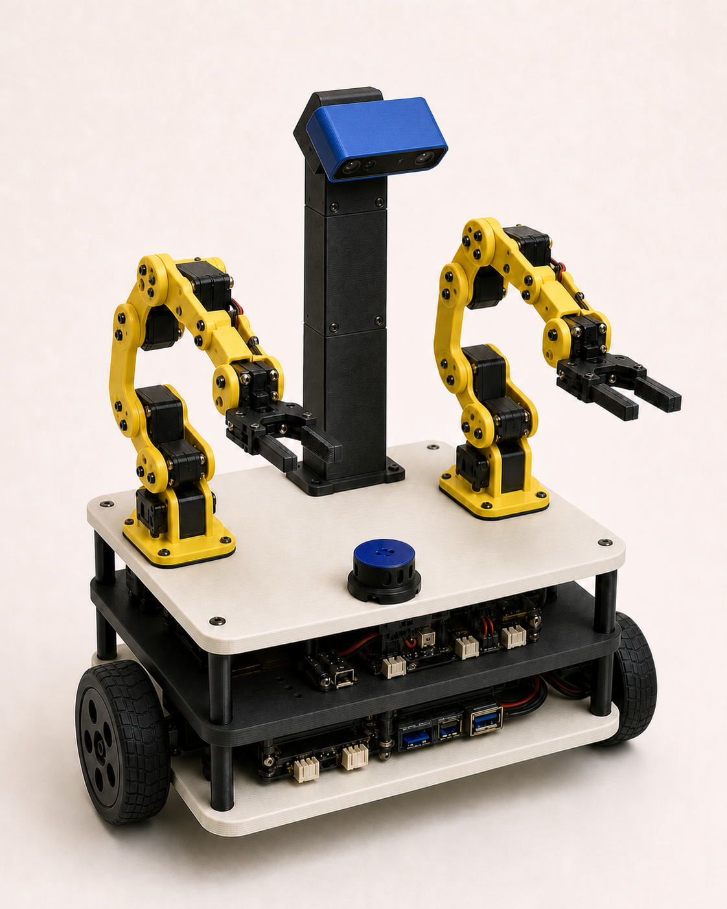
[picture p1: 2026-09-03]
design/renders/hold_flow_model_concept_v3.png

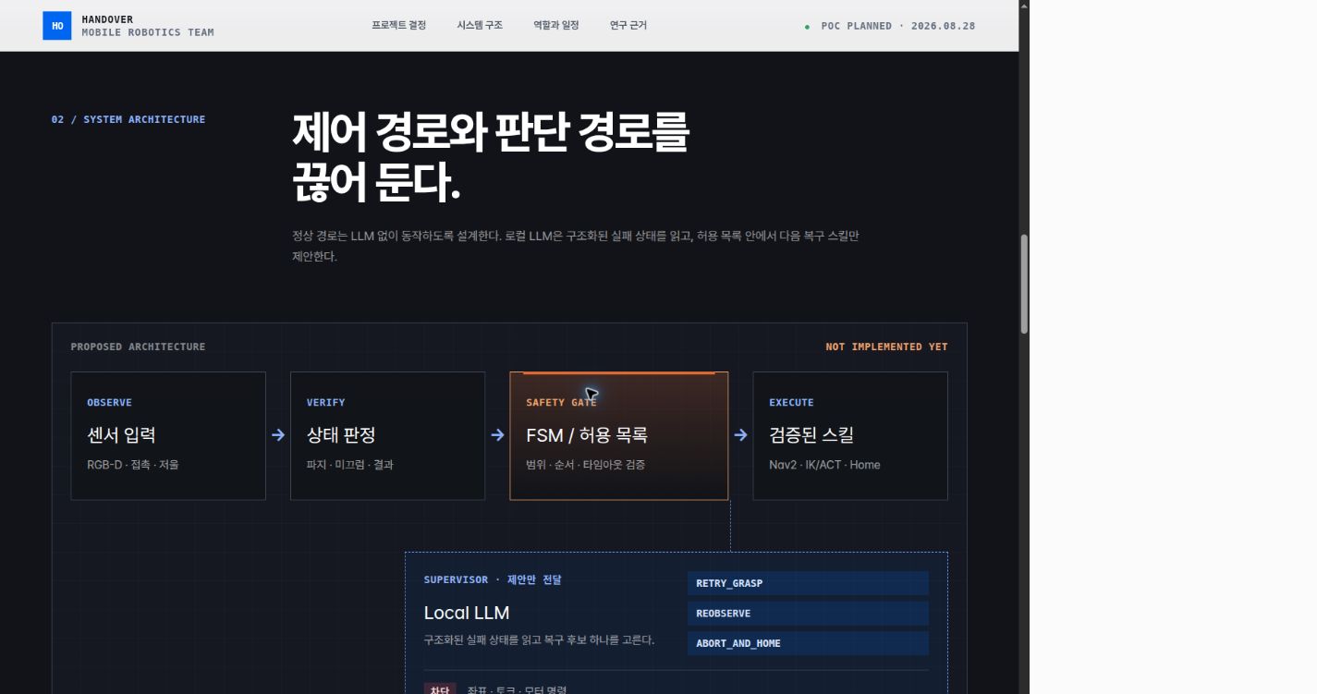
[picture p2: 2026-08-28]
docs/site-preview/20260828_hold-the-flow_architecture-v6.jpg

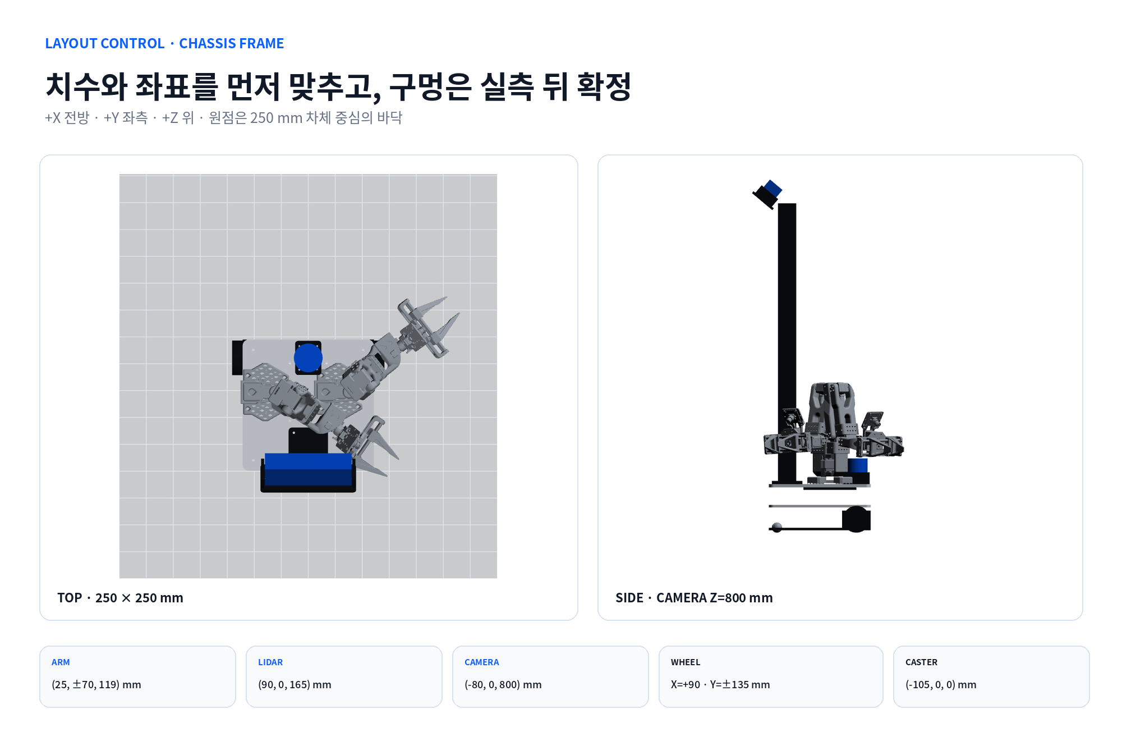
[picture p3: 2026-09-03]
docs/assets/design_handoff/03_layout_reference.png

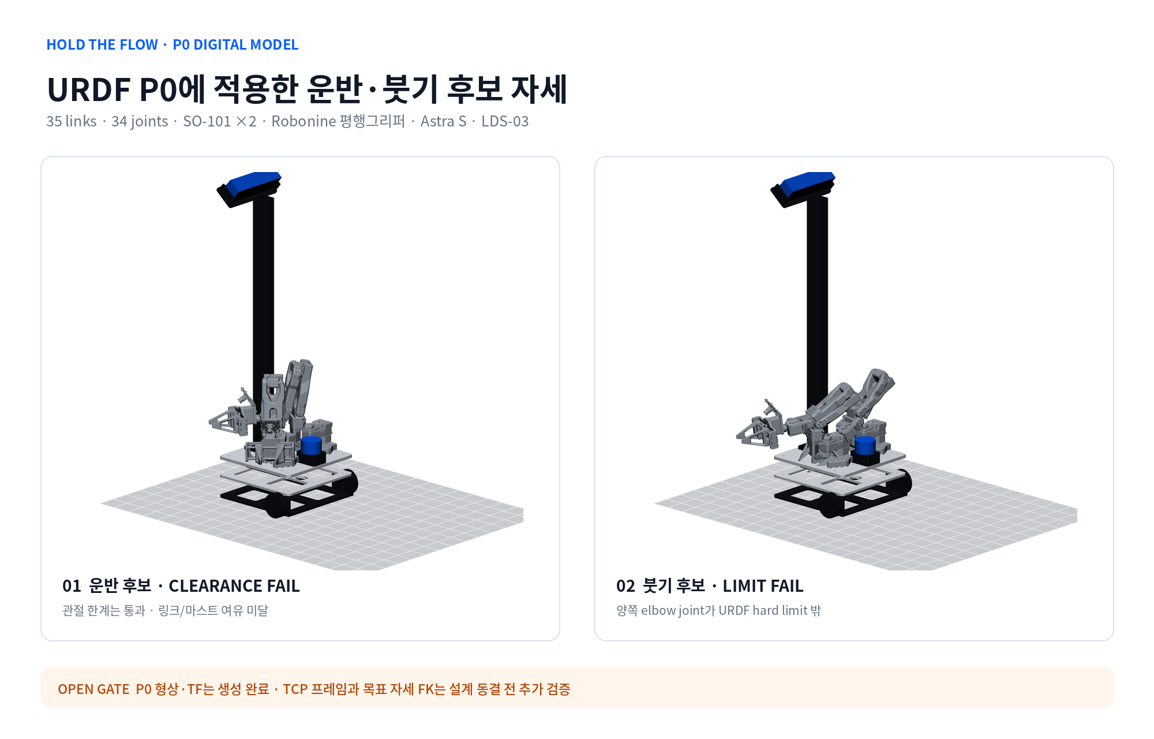
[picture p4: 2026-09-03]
docs/assets/design_handoff/01_p0_model_status.png

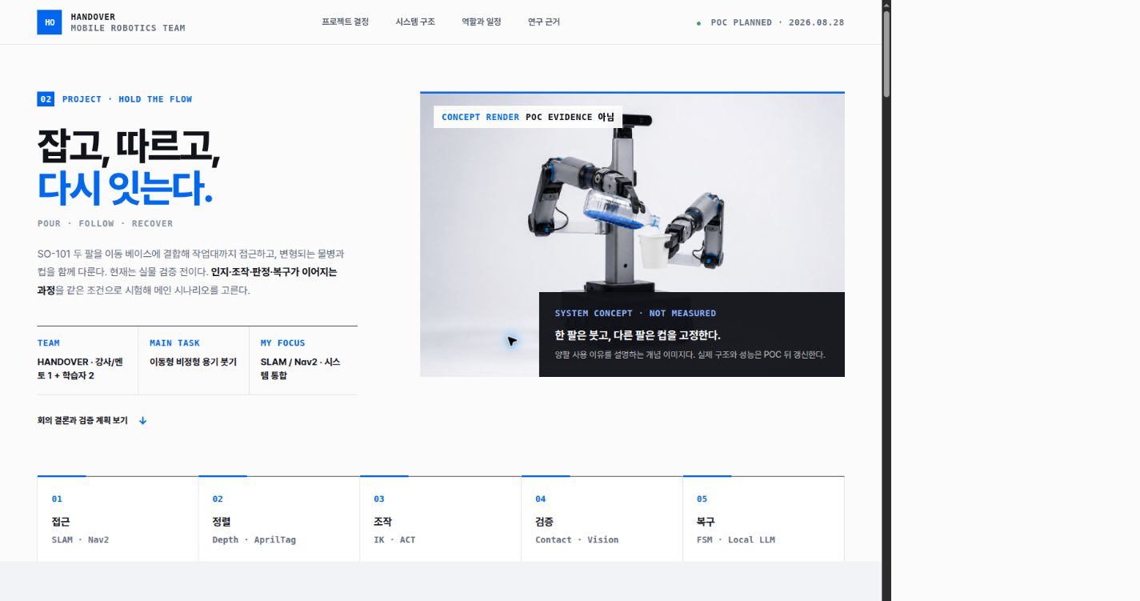
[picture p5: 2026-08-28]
docs/site-preview/20260828_hold-the-flow_live-v5.jpg

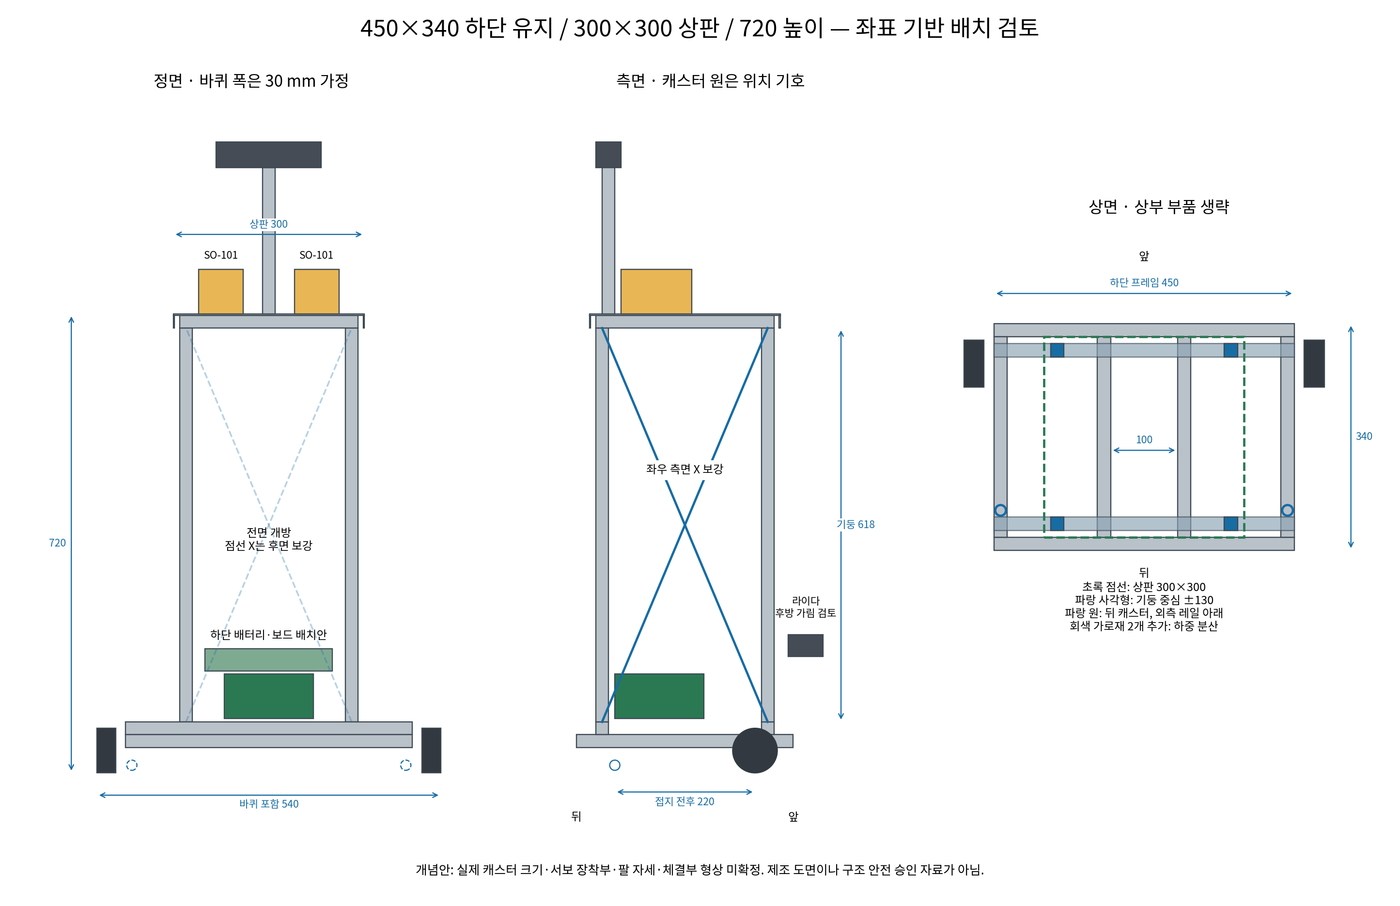
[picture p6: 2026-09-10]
docs/assets/raised_frame_20260909/coordinate_layout.png

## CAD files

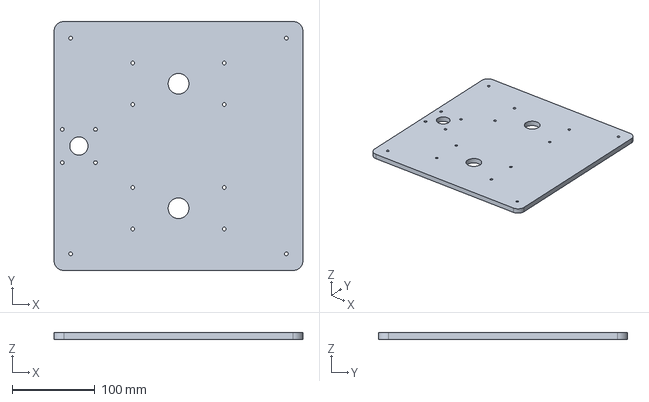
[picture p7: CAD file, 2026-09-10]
design/cad/exports/step/chassis_top.step
300.0 x 300.0 x 8.00 mm

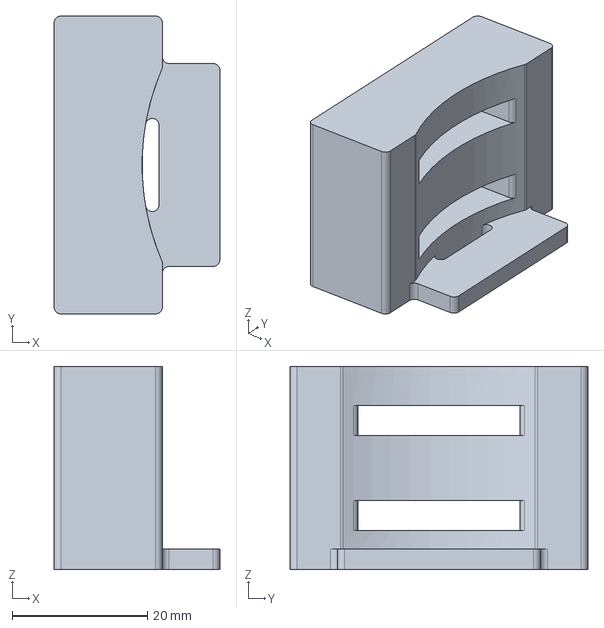
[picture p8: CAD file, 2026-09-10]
design/gripper/exports/cup_overcaps/step/so101_cup_overcap.step
24.5 x 44.0 x 30.0 mm

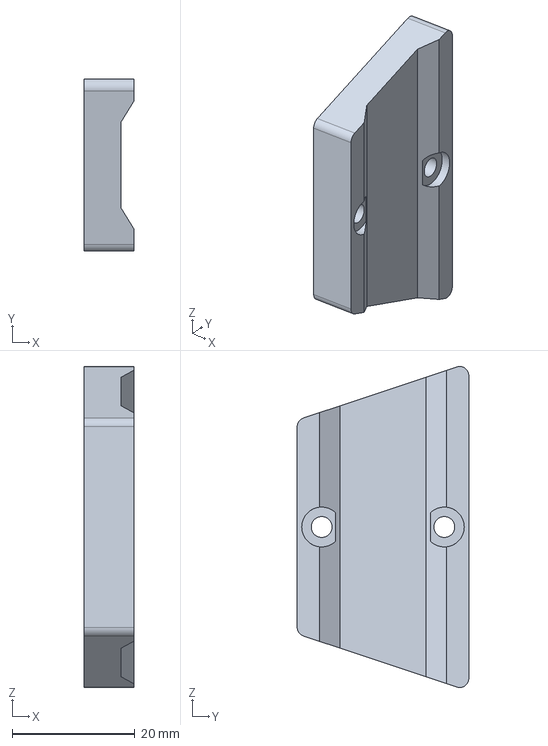
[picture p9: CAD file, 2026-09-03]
design/gripper/exports/step/insert_C_trapezoid.step
8.07 x 28.0 x 52.3 mm

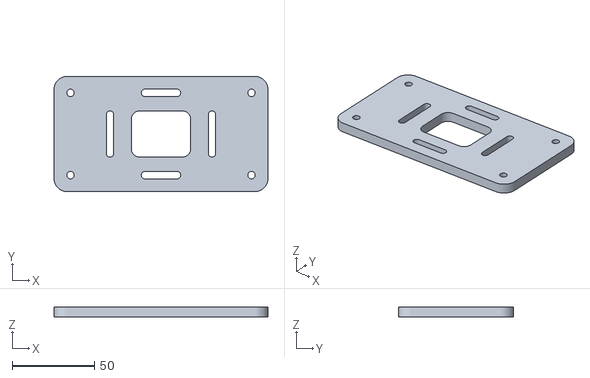
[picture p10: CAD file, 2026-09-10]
src/hold_flow_description/meshes/cad/arm_adapter.stl
130.0 x 70.0 x 6.00

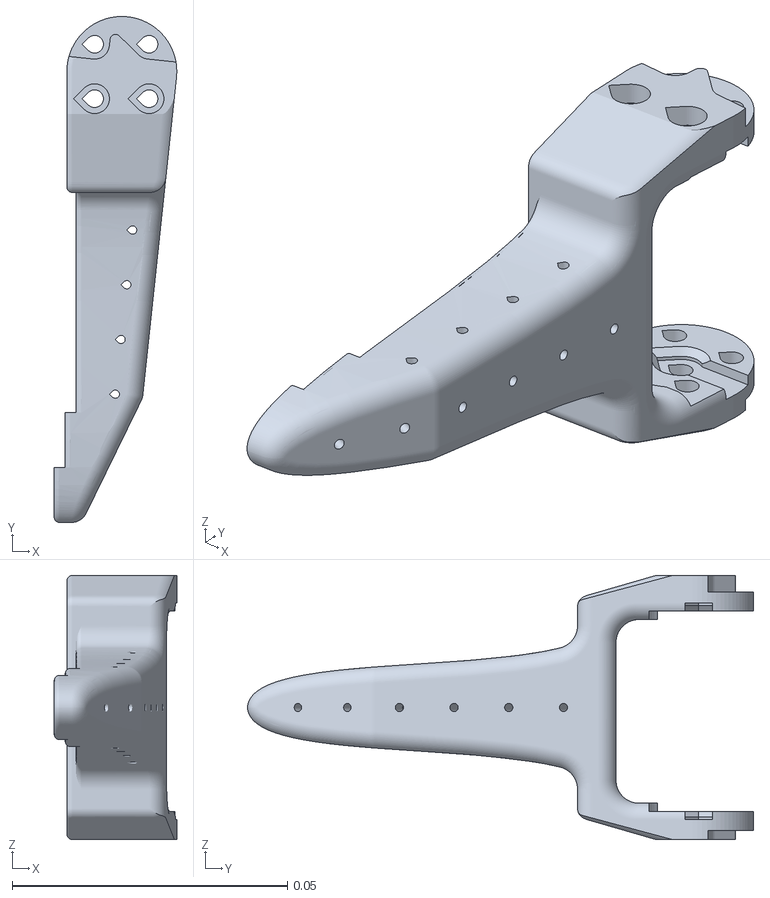
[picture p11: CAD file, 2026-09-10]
src/hold_flow_description/meshes/so101/moving_jaw_so101_v1.stl
0.0223 x 0.092 x 0.048

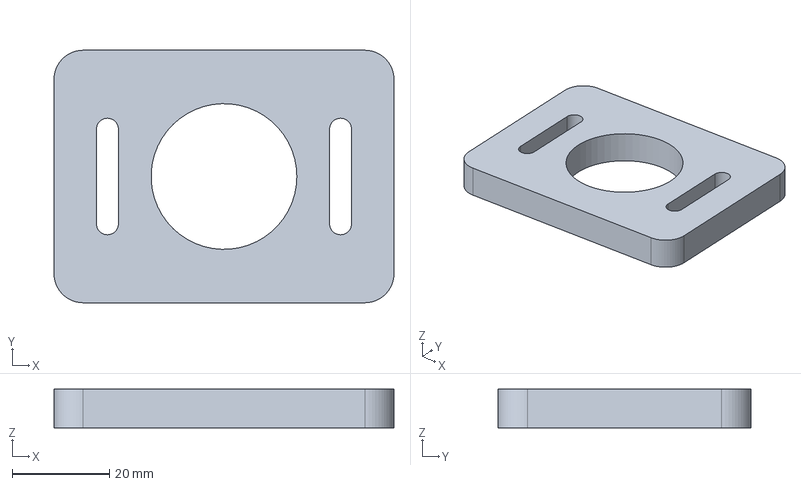
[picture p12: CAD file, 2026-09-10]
design/cad/exports/step/rear_caster_adapter.step
70.0 x 52.0 x 8.00 mm

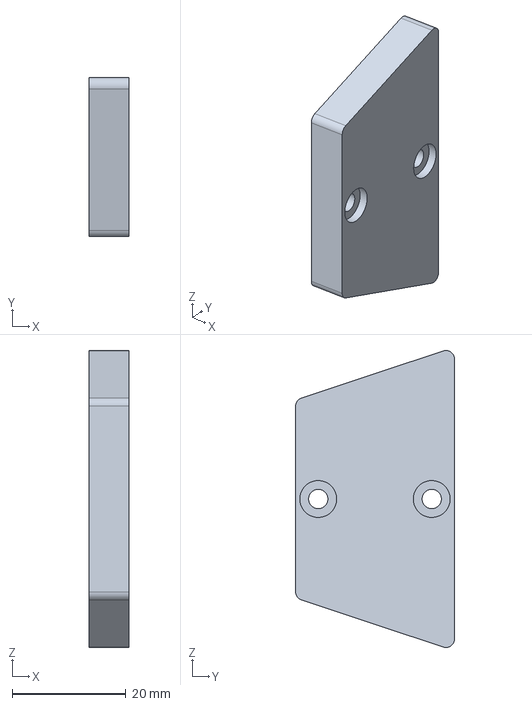
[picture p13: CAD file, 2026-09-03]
design/gripper/exports/step/insert_A_flat_pad.step
7.00 x 28.0 x 52.3 mm

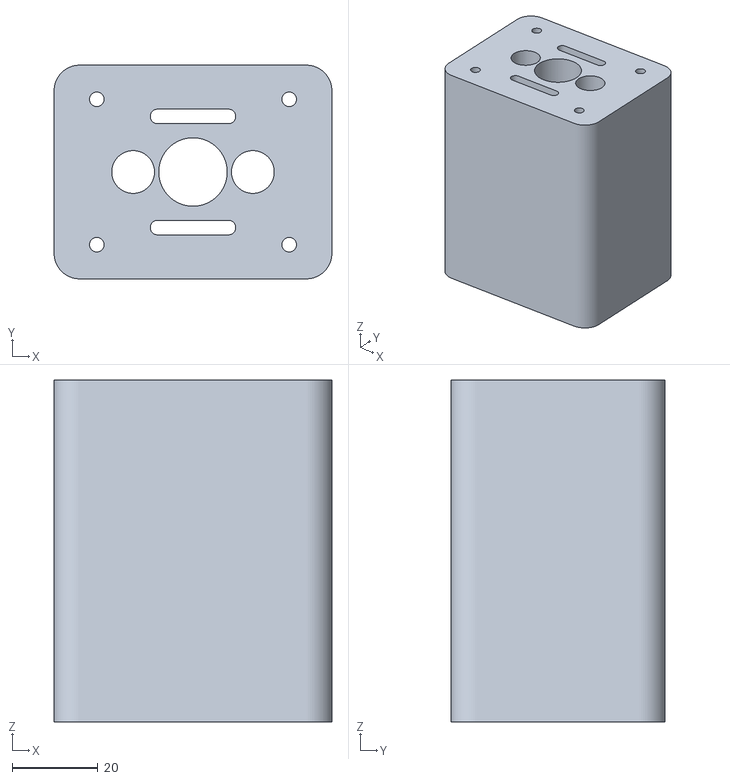
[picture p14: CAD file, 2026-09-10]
src/hold_flow_description/meshes/cad/lidar_riser.stl
65.0 x 50.0 x 80.0

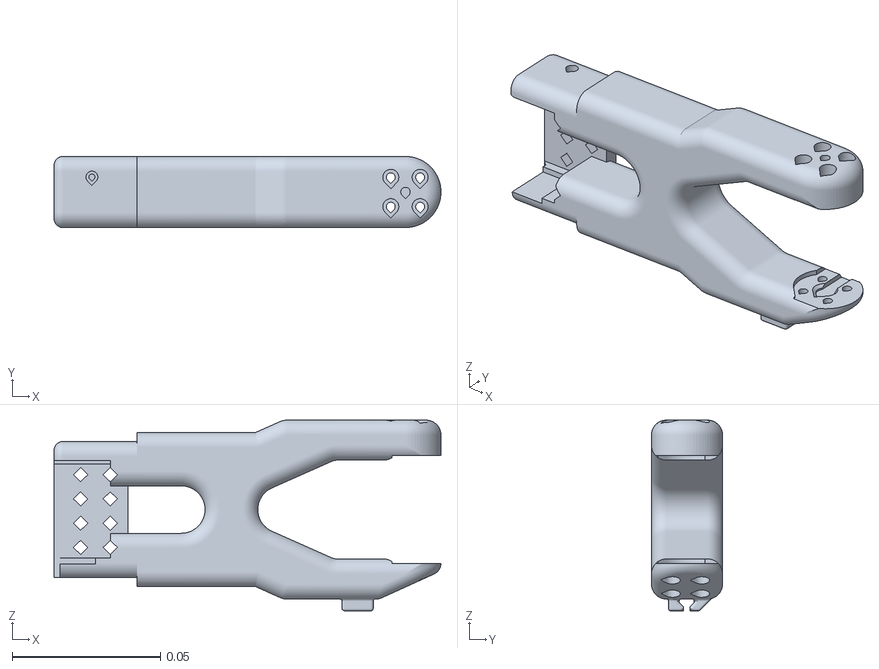
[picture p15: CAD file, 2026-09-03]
src/hold_flow_description/meshes/so101/under_arm_so101_v1.stl
0.131 x 0.024 x 0.0644

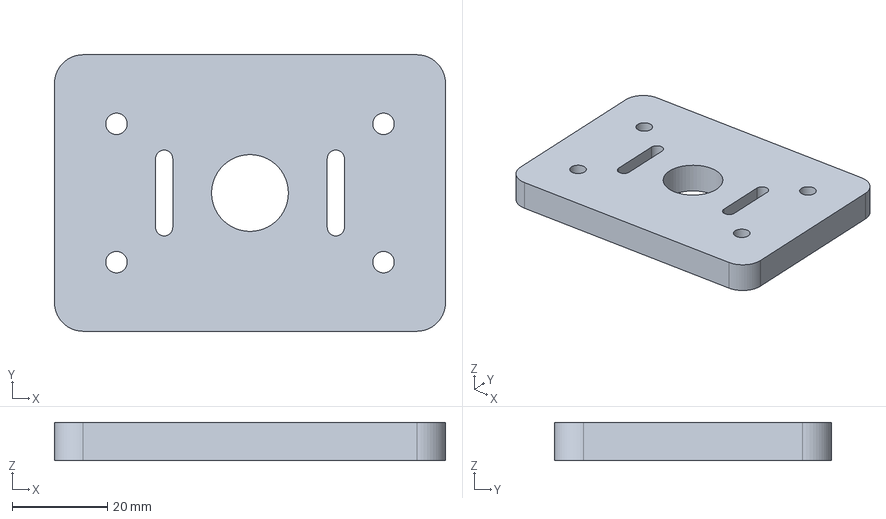
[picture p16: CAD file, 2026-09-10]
design/cad/exports/step/drive_side_carrier.step
82.0 x 58.0 x 8.00 mm

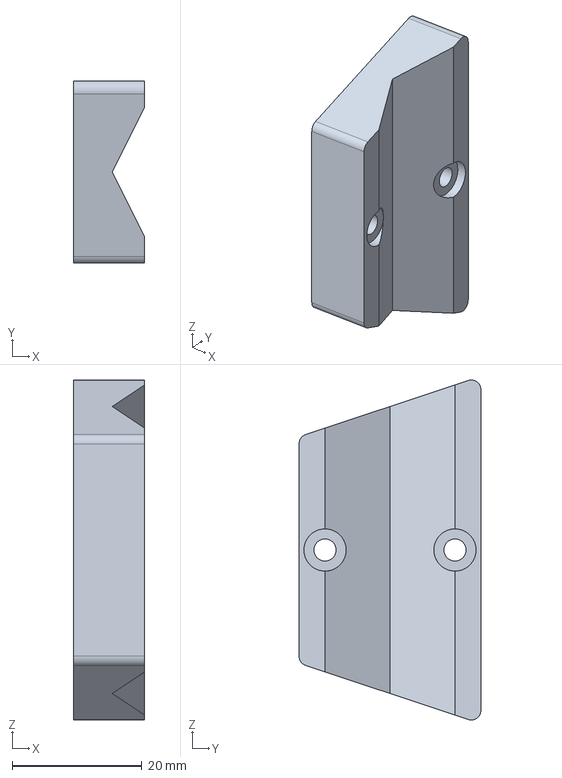
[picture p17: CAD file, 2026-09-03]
design/gripper/exports/step/insert_B_v_groove.step
11.0 x 28.0 x 52.3 mm

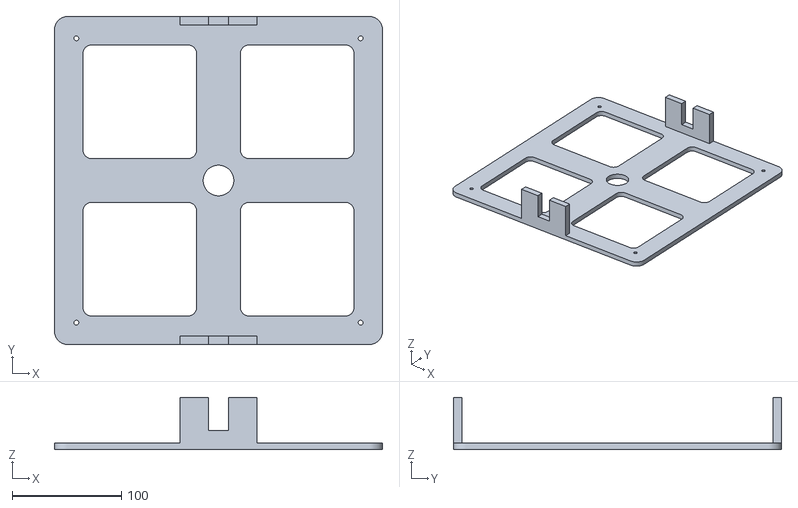
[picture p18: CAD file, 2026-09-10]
src/hold_flow_description/meshes/cad/chassis_bottom.stl
300.0 x 300.0 x 48.0

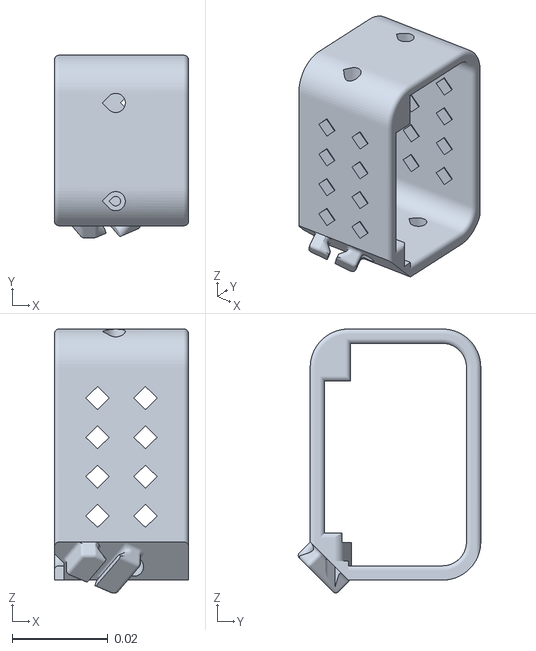
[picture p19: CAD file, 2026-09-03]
src/hold_flow_description/meshes/so101/motor_holder_so101_base_v1.stl
0.028 x 0.0381 x 0.0551

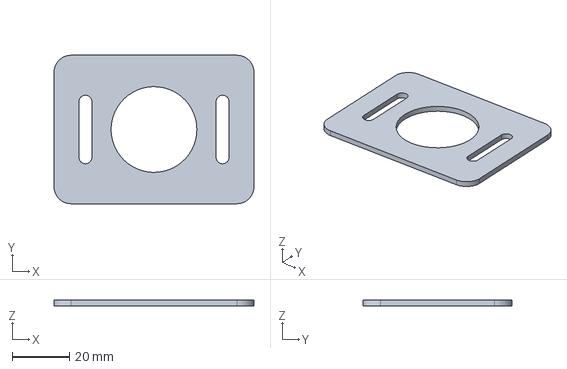
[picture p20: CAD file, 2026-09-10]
design/cad/exports/step/rear_caster_shim_2mm.step
70.0 x 52.0 x 2.00 mm

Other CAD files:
src/hold_flow_description/meshes/cad/chassis_middle.stl
src/hold_flow_description/meshes/so101/base_motor_holder_so101_v1.stl
design/cad/exports/step/lidar_riser.step
src/hold_flow_description/meshes/cad/frame_column.stl
design/cad/exports/step/arm_adapter.step
design/cad/exports/step/astra_cradle.step
design/cad/exports/step/camera_backing.step
design/cad/exports/step/camera_mast_coupler.step
design/cad/exports/step/camera_mast_segment.step
design/cad/exports/step/chassis_bottom.step
design/cad/exports/step/chassis_middle.step
design/cad/exports/step/coupon_m1_coupler_stub.step
design/cad/exports/step/coupon_m1_fit_plug.step
design/cad/exports/step/coupon_m1_fit_socket.step
design/cad/exports/step/coupon_m1_holes.step
design/cad/exports/step/coupon_m1_mast_stub.step
design/cad/exports/step/frame_column.step
design/cad/exports/step/hold_flow_printed_structure.step
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

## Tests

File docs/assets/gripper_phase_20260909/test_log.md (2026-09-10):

# 실물 테스트 로그 — 2026-09-09 그리퍼 서보 ID 6

터미널 출력을 그대로 옮긴 것이다. 해석은 [사고 분석 문서](../../20260909_그리퍼_서보_Phase반전_사고분석.md)에 있다.
보드: 팔로워 `5B3D046653` (12 V). 서보: STS3215, ID 6, ggao50 랙-피니언 그리퍼.

## 이탈 사고 4건 (발산 감지 도입 전)

| # | 직전 상태 | 명령 | 결과 |
|---|---|---|---|
| 1 | 열림 732 (오프셋 −1745, 한계 763~3600) | `goto --goal 3000 --max-delta 2400 --speed 200` | 열림 쪽으로 달아나 레일 이탈 |
| 2 | 열림 687 (재조립 후) | `goto --goal 950 --max-delta 400 --speed 150` | 열림 쪽으로 달아나 레일 이탈 |
| 3 | 2082 (오프셋 408, 한계 800~3540) | `goto --goal 1200 --max-delta 1200 --speed 150` | 1821 에서 멈춤, 열림 쪽 이탈 |
| 4 | 열림 580 (오프셋 1719, 한계 680~3480) | `goto --goal 2900 --max-delta 2400 --speed 150` | 열림 쪽으로 달아나 레일 이탈 |

공통점: **목표값이 위든 아래든, 시작이 어디든, 물리적으로 항상 열림 끝으로 달아났다.**

## 발산 감지 도입 후 (이탈 0건)

`servo_goto.py` 에 "목표에서 시작 오차보다 20 카운트 이상 멀어지면 즉시 구동 차단" 을 넣은 뒤의 기록.

### 5. 영점 2048 · 한계 370~3180 · 보호값 원래(25%/0.5 s) · Phase 12

```
ID 6  현재 327  목표 800  델타 +473 (+41.6도)  한계 370~3180  온도 35C
  발산: 목표에서 멀어짐 (오차 473->498). 모터-엔코더 극성 반대 의심 -> 정지·구동해제. 위치 294
```
→ 위로 보냈는데 아래로 33 이동. 3 mm 에서 정지, 이탈 없음.

### 6. 오프셋 0 · 한계 0~4095 · 보호값 원래

```
python3 servo_goto.py --port $F --goal 1554 --max-delta 400 --speed 100 --diverge-tol 20 --execute
```
→ 2회 모두 열림 방향, 발산 정지 (출력 미보존). 직후 읽기: 위치 1204, 목표 레지스터 1208.

```
python3 servo_goto.py --port $F --goal 904 --max-delta 400 --speed 100 --diverge-tol 20 --execute
```
→ 반대 방향 목표. 역시 열림 방향, 발산 정지 (출력 미보존).

### 7. 보호값 복원 후 (MaxTq 1000 · OvldTq 80 · ProtTime 200 · ProtCur 320) · Phase 12

```
ID 6  현재 1315  목표 1515  델타 +200 (+17.6도)  한계 0~4095  온도 35C
  발산: 목표에서 멀어짐 (오차 200->223). 모터-엔코더 극성 반대 의심 -> 정지·구동해제. 위치 1290
ID 6  현재 1290  목표 1515  델타 +225 (+19.8도)  한계 0~4095  온도 35C
  발산: 목표에서 멀어짐 (오차 225->247). 모터-엔코더 극성 반대 의심 -> 정지·구동해제. 위치 1266
```
→ 보호값은 원인이 아님.

### 8. Phase 12 → 76 (재부팅 없이)

```
ID 6  현재 2301  목표 2501  델타 +200 (+17.6도)  한계 0~4095  온도 36C
  발산: 목표에서 멀어짐 (오차 200->223). 모터-엔코더 극성 반대 의심 -> 정지·구동해제. 위치 2275
ID 6  현재 2275  목표 2501  델타 +226 (+19.9도)  한계 0~4095  온도 35C
  발산: 목표에서 멀어짐 (오차 226->247). 모터-엔코더 극성 반대 의심 -> 정지·구동해제. 위치 2252
```
→ 그대로. Phase 는 재부팅 후 적용되는 레지스터.

### 9. 12 V 재투입 후 (Phase 76 유지 확인)

```
재부팅 후  Phase 76  MaxTq 1000  TqLim 1000  OvldTq 80  ProtTime 200  위치 2250  구동 0  전압 12.3V
```
```
python3 servo_goto.py --port $F --goal 2450 --max-delta 300 --speed 100 --diverge-tol 20 --execute
```
→ **도달.** 직후 읽기: 위치 2445, 목표 레지스터 2445, 부하 0. 죠는 닫히는 방향으로 움직임.

## 정지 상태 두 점 읽기 (방향·행정 확정용, 서보 무동작)

| 시점 | 오프셋 | 완전 열림 | 완전 닫힘 | 행정 |
|---|---|---|---|---|
| 09-07 | −1075 | 732 | 3600 | 2868 |
| 09-09 오프셋 0 | 0 | 2328 | 1112 | (경계 넘음) 2880 |
| 09-09 영점 2048 | 960 | 327 | 3212 | 2885 |

세 번 모두 행정 ≈ 2870~2885 카운트 ≈ 95 mm 로 일치. 기구는 그대로였다는 증거.

## EEPROM 대조 (수정 전, 팔로워 ID 6 만 다른 항목)

| 주소 | 이름 | F1~F5 | **F6** | 리더 L6 |
|---|---|---|---|---|
| 18 | Phase | 12 | **12** | 76 |
| 33 | Mode | 0 | 0 | 0 |
| 16/17 | Max Torque | 1000 | **500** | 500 |
| 36 | Overload Torque | 80 | **25** | 25 |
| 35 | Protection Time | 200 | **50** | 200 |
| 28/29 | Protection Current | 320 | **250** | 250 |

수정 후 전체 덤프: [`eeprom_after_fix.json`](eeprom_after_fix.json).
오프셋·한계 변경 이력: [`servo_backup_log.jsonl`](servo_backup_log.jsonl).

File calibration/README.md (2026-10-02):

# 캘리브레이션 상태

현행 왼손은 TPU FinRay가 아니라 SO-101 순정 회전식 죠를 사용한다.

## 현행 양팔 · 2026-10-02

PR [#54](https://github.com/mmporong/bimanual-robot/pull/54)의
`c75a93d2a173bd9bfff73e739b5b7a6df5f057a4`에서 갱신한 양팔 follower와
오른쪽 leader JSON을 현행 기준으로 채택했다. 팀원은 그리퍼 축 재조립 후
여유를 적용한 범위를 기록했다. follower 파일에는 그리퍼 외 관절의 영점·범위
변경도 있으므로 기존 파일의 그리퍼 항목만 섞지 않고 새 JSON 전체를 사용한다.

| 용도 | 현행 파일 | ID 6 방향 | ID 6 범위 (tick) |
|---|---|---|---|
| 왼팔 follower, 순정 죠 | `bi_follower/arms_left.json` | `drive_mode=0` | 1452~2845 |
| 오른팔 follower, ggao50 | `bi_follower/arms_right.json` | `drive_mode=1` | 1209~3999 |
| 오른팔 leader | `bi_leader/arms_right.json` | `drive_mode=0` | 2049~3303 |

파일 SHA-256:

- 왼팔 follower: `e4c89b7ef2226a3ce9ae49e5a5cfbc0501705ec62e7fa2aab40f80d1114ee56f`
- 오른팔 follower: `00bc7e362024ef95a4ee27fe8b9b02210571c1aae5d565933dc9ee2043462f06`
- 오른팔 leader: `76864f87f603de73557cc372079f0deb9f486c9c5abeff2886f12e8d2f50f90d`

왼팔 leader는 기존 `bi_leader/arms_left.json`을 유지한다. 단일팔 폴더의
`so_follower/follower.json`, `so_follower_left/follower_left.json`,
`so_leader/leader.json`은 과거 사본이며 현행 양팔 파일을 덮어쓰는 원본이 아니다.
양팔 텔레옵·녹화는 `robot.id=arms`, `teleop.id=arms`와 `bi_follower`·`bi_leader`
폴더를 지정한다. LeRobot 로컬 캐시를 자동으로 교체하지 않는다.

이번 반영은 저장소 파일·문서의 통합이다. EEPROM 재판독·쓰기나 팔 동작으로
새 JSON과 현재 연결 기체의 일치를 확인한 것은 아니다. 팀원의 커밋에는 오른팔
ID 6의 `Overload_Torque` 25→80%, `Max_Torque` 500→1000,
`Protection_Current` 250→320 복원 기록이 있다. 이 설정은 JSON 보정과 별개인
EEPROM 기록이며, JSON을 받는 것만으로 적용되거나 이번 병합에서 다시 쓰이지 않는다.

기존 IK mapping·joint reference·snapshot·pregrasp 후보·계획 packet은 보정 해시가
달라졌으므로 재사용하지 않는다. 새 JSON으로 현재 상태와 계획을 다시 생성한다.
해시 검사나 관절 한계를 완화해서 이전 계획을 통과시키지 않는다. URDF 기하는 보정
파일 변경만으로 수정하지 않으며 영점·TCP·개구 대응은 별도 확인 대상이다.
기존 IL 데이터·checkpoint의 정규화도 수집 당시 보정과 대조한 뒤 평가한다.

이전 활성 JSON 3개는 Git의 `9720d6f`와 로컬
`$HOME/.local/state/bimanual-robot/calibration-pr54-20261002.5K71fR/calibration/`에 보존했다.
아래 기록의 토크·전원·연결·시험 결과는 각 날짜 당시 상태이며 현재 기체 상태가 아니다.

## 이전 기록 · 2026-09-30

사용자가 중간 자세 설정과 가동 범위 기록을 마쳐 공식 LeRobot
`SOFollower.calibrate()`의 왼팔 보정을 완료했다. 일반 연결 시 설정 변경은
실행하지 않았고 기존 게인·Phase를 유지했다. 새 후보와 보드의 offset·범위를
대조하고 6축 토크 OFF를 확인한 뒤 `bi_follower/arms_left.json`에 반영했다.
당시 오른팔 보정은 아래 2026-09-29 기록을 유지했다.

- 왼팔 ID 6: `drive_mode=0`, raw `2028~3483`; 손목 롤 범위는 관례값 `0~4095`다.
- 백업·실측 후보·종료 검증·새 snapshot: `/data/lim/robot-artifacts/restaurant/standard_calibration_20260930_left01/`.
- 활성 파일 SHA-256: `69b3a38747f7f143670f795808beaeedaeffb6114a5b9b076e6cc330701e7fbe`.
  공식 후보와 JSON 값은 같고 활성 파일에만 마지막 개행이 있다. 후보·snapshot의
  바이트 해시는 `9a9328bec2bc350e69d75989bdb0c8c8231c875bf02cb15faafcf86477713873`이다.
- 보정 기록 완료는 IK 좌표 정밀도나 컵 파지 성공이 아니다. 종료 자세의 어깨 각도는
  명목 URDF 하한 밖으로 계산되며, URDF 한계나 좌표를 임의 수정하지 않았다.
- 이전 raw 목표·계획 packet은 재사용하지 않는다. 기존 IL 정책·데이터도 이전
  보정의 정규화를 사용했으므로 새 보정과의 호환을 검증하기 전 실행하지 않는다.
  리더·LeRobot 캐시·기존 데이터셋은 변경하지 않았다.

## 이전 기록 · 2026-09-29

2026-09-29 실기체 연결에서 저장소 JSON과 보드의 오프셋 차이를 확인했다.
사용자 승인으로 양팔 범위를 수동 기록하고 MIN/MAX만 EEPROM에 적용했다.
IK 실행 준비의 기준은 `bi_follower/arms_left.json`과 `bi_follower/arms_right.json`이다.
이 JSON은 새 범위와 현재 보드 오프셋을 반영한다. 보드 홈오프셋·Phase·게인은 바꾸지 않았다.

| 팔 | 보드 by-id 끝부분 | 그리퍼 | JSON 방향 | ID 6 Phase | 적용 범위 |
|---|---|---|---|---|---|
| 왼팔 | `5B3E088747-if00` | SO-101 순정 | `drive_mode=0` | 12 | 1340~2834 tick |
| 오른팔 | `5B3D046653-if00` | ggao50 순정 | `drive_mode=1` | 76 | 526~3416 tick |

오른손은 관측 끝점 486~3456 tick에서 양 끝을 40 tick씩 줄였다.
양팔 wrist_roll은 관례대로 0~4095이며, 롤 끝점을 수동으로 측정한 값은 아니다.
오프셋·한계값·Phase·P/D/I·잠금 상태를 적용 후 다시 읽어 대조했고, 12개 서보 토크는
모두 OFF였다. 이 대조는 새 범위의 저장을 확인한 것이며 동작 정밀도를 입증하지 않는다.

현재 상태는 **전원 재인가 후 대조·작은 개폐 시험 통과**다. 사용자의 12V 전원
재인가 완료 확인 후 양팔 offset·한계·Phase·토크 OFF·잠금을 다시 읽어 대조했다.
그리퍼 ID 6만 현재 위치에서 열림 방향 128 tick, 시작점 기준 64 tick 위치로 부분
되닫기했다. 왼손은 raw 증가, 오른손은 raw 감소를 열림 방향으로 사용했다.
위치 도달 판정의 허용 오차는 16 tick이다. 두 방향의 서보 위치 변화만 확인한 것이며,
전체 개구·죠의 실제 이동·끝점 여유·TCP·컵 파지 검증을 대체하지 않는다.

오른손 첫 시험은 위치 동작 후 최종 토크가 1로 관측돼 실패 처리했다. OFF 재전송 후
해제를 확인했고, 설정 복원 뒤 OFF를 마지막으로 보내 대조하는 종료 처리로 보완했다.
같은 크기의 재시험은 종료까지 통과했다. 최초 실패 원인은 미확정이며 원본 로그를 보존했다.
현재 양팔 12개 서보는 OFF다. 온도·부하는 기록·적용·작은 개폐 시험에서 읽지 않는다.
이후 전원 재인가에서도 팔을 받치고, 전원이 켜진 상태에서 서보 연결선을 탈착하지 않는다.

기록·백업·적용 전후 대조는 로컬 `/data/$USER/robot-artifacts/restaurant/calibration_20260929.BVaxly/`
의 후보 JSON 및 `left_apply01/journal.jsonl`, `right_apply01/journal.jsonl`에 보존했다.
작은 개폐 결과는 `left_gripper_physical01.json`, `right_gripper_physical01.json`(종료 실패),
`right_gripper_physical02.json`(재시험 통과)에 있다. 오른손 해제 확인은
`right_gripper_release01.json`과 `right_gripper_after_release01.json`에 따로 기록했다.
원시 기록은 Git에 넣지 않는다. 적용 도구와 복구 조건은
[`tools/servo/README.md`](../tools/servo/README.md#기존-오프셋을-유지하는-범위-갱신)에 있다.

리더 파일, 단일팔 과거 사본, LeRobot 로컬 캐시는 이번에 바꾸지 않았다.
이들을 새 양팔 기준으로 혼용하거나 과거 IK raw 목표를 재사용하지 않는다.
새 JSON으로 계획을 다시 만들고, 기존 IL 정책도 관측·action 정규화가 같은지 대조한 뒤 시험한다.
TCP·카메라 보정과 실물 파지 정밀도 검증은 별도다.

기구를 다시 변경하거나 파일과 실물 설정이 어긋난 경우에만 다음 순서로 갱신한다.

1. 완전 개폐의 기구 간섭과 서보 방향을 확인한다.
2. 순정 죠의 ID 6 원시 끝점과 안전 여유를 측정한다.
3. 새 후보 파일에 범위를 기록하고 시작 전 EEPROM 백업과 대조한다.
4. 한계값 적용·전원 재인가·읽기 대조를 거쳐 양팔 follower JSON을 확정한다.
5. 마른 컵·젖은 컵 파지와 선반 재파지를 다시 시험한다.

새 측정 없이 참고값이나 추정값을 JSON에 넣지 않는다. 상세 절차와 과거
값은 [`docs/20260909_그리퍼_캘리브레이션_인계.md`](../docs/20260909_그리퍼_캘리브레이션_인계.md)에 있다.

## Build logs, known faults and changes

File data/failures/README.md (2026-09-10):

# 실패 데이터 저장·진단·활용 규약

실패 데이터의 목적은 실패 영상을 모으는 것이 아니라, **관측된 증상과 확인된 원인을
분리하고 수정 뒤 같은 조건에서 다시 검증하는 것**이다. 한 번 성공한 데모보다 어떤 계층의
문제인지 근거로 좁힌 기록을 남긴다.

이 디렉터리에는 실영상·rosbag·trajectory를 커밋하지 않는다. 대용량 근거는 데이터셋과
함께 Hugging Face Hub(private) 또는 팀 artifact storage에 두고, 저장소에는 스키마·작성
예시·집계 규칙만 둔다.

## 1. 저장 단위

`failure_id`는 한 원인 조사를 식별한다. `source.run_id`는 조사를 시작한 대표 실행이며,
같은 조사에 속하는 추가 조작 실행은 각 episode sidecar의 `run_id`와 동일한
`failure_record_id`로 연결한다. 재시험은 `validation`의 run ID와 근거 파일로 연결한다.
추가 실행의 개별 조건·관측을 대표 실행의 `context` 위에 덮어쓰지 않는다.
Nav2 등 sidecar가 없는 추가 발생은 별도 실패 레코드로 기록해 관측과 조건을 보존한다.

따라서 실패 레코드 수는 실패 발생 횟수와 다르다. 발생 빈도·성공률은 성공 실행도 포함한
전체 run 목록을 분모로 계산해야 한다. 현재 집계 도구는 분석 레코드 수만 보고한다.

```text
private-artifacts/
└── failures/
    └── FAIL-YYYYMMDD-NNNN/
        ├── failure.json
        ├── evidence/
        │   ├── before.mp4
        │   ├── run.mcap
        │   ├── nav_arrival.json
        │   ├── joint_action_window.parquet
        │   └── fill_measurement.json
        └── validation/
            ├── same_condition_runs.json
            └── regression_runs.json
```

- `failure.json`: `failure_record.schema.json`을 통과하는 분석 레코드
- `before.mp4`: 실패 직전과 직후가 포함된 영상 구간
- `run.mcap`: 필요한 토픽만 보존한 실행 기록
- `*_window.parquet`: 실패 전후 관측·action·실측 관절값
- `validation/`: 수정 뒤 같은 조건과 다른 조건을 다시 실행한 결과
- 모든 URI는 이동해도 다시 찾을 수 있는 안정 경로를 사용하고, 가능하면 SHA-256을 남긴다.

## 2. 두 종류의 기록을 연결한다

### 에피소드 sidecar

`episode_metadata.schema.json`은 빠른 집계용이다. 실패 여부, 실패 단계, 관측된 failure code,
이상 현상과 `failure_record_id`를 저장한다.

### 실패 분석 레코드

`failure_record.schema.json`은 원인 분석용이다.

```text
관측 observation
→ 실행 조건 context
→ 근거 evidence
→ 가설과 확정 원인 diagnosis
→ 즉시 조치와 수정 response
→ 동일 조건·회귀 재시험 validation
→ 학습·평가 데이터 사용 결정 data_use
```

`CUP_GRASP_MISS`, `UNDER_FILL`, `TIMEOUT`은 관측된 결과다. 이를 곧바로 `ACT 데이터 부족`,
`YOLO 오류`, `서보 고장` 같은 원인으로 기록하지 않는다.

## 3. 필수 캡처 구간

| 경계 또는 단계 | 함께 보존할 데이터 | 구분하려는 원인 |
|---|---|---|
| Nav2 → 조작 시작 | 목표·실제 pose, XY·yaw 오차, covariance, 베이스 속도, TF age, 로컬 정렬량, IK 도달성 | 조작 실패와 도착·정렬 실패 |
| 조작 phase | `control_strategy`·backend·phase, checkpoint 또는 planner·trajectory·controller·config, 영상, 관측/action/관절 window, 그리퍼, inference·계획 시간, 제어 지터, 안전 게이트 | 인지·계획·데이터·정책·실행기·하드웨어 실패 |
| 물 양 판정 | target·YOLO 추정·저울 실측 mL, mask, confidence, 가림, calibration ID, 물통 기울기·시간 | segmentation·보정표·붓기 제어 실패 |
| Isaac Sim ↔ 실물 | URDF commit, 관절 축·방향·한계, 동일 관절값의 말단 pose, 충돌·접촉, 지연 | 모델 오류와 제어·물성 gap |
| 미션 전이 | request/run ID, 상태 진입·종료 시각, Action 결과·취소, timeout, 센서 최신성 | 상태기계·인터페이스 실패 |

원인 판단에 쓰지 않을 데이터는 무작정 늘리지 않는다. 실패 시각 기준의 앞뒤 구간과
clock 기준을 정해 영상·관절·action·센서의 동일 시점을 연결한다. 구간을 잘라도 원본 URI와
시작·종료 오프셋을 남긴다. 로그 보존 기간은 실제 파일 크기와 저장 예산을 측정한 뒤 정한다.

## 4. 실패 처리 순서

1. `run_id`와 `failure_id`를 발급하고 `triage_owner`와 안전 정지 여부를 기록한다.
2. `observation`에는 보인 현상만 적고 `cause_status=untriaged`로 시작한다.
3. 실패 전후 영상·관절/action·Nav2·인지·안전 데이터를 evidence ID로 연결한다.
4. 원인 후보마다 가설을 만들고 `pending / rejected / supported`를 기록한다.
5. 근거가 생긴 경우에만 `cause_status=confirmed`와 `root_cause`를 채운다.
6. 정책 재학습, 보정 수정, station 수정, 기구 수정 중 필요한 조치만 선택한다.
7. 수정한 뒤 같은 조건을 다시 실행하고, 다른 조건의 회귀도 따로 확인한다.
8. 실패 원본을 학습·평가·HIL 중 어디에 사용할지 `data_use`로 결정한다.

원인을 확인하지 못했으면 `unresolved`로 남긴다. `OTHER`나 자유 메모로 억지 결론을 만들지
않는다.

같은 조건에서 반복 실패하면 로직만, 조건별로 성능이 다르면 데이터만 문제라고 단정하지
않는다. 둘 다 원인을 좁히는 단서다. 고정된 정책 편향도 반복 실패를 만들고, 센서·기구
문제도 조건에 따라 달라질 수 있다. 측정값의 유효성을 먼저 확인한 뒤 가설별 대조를 남긴다.

## 5. 학습 데이터와 실패 데이터의 사용 구분

| 데이터 | BC 학습 포함 | 보존·활용 |
|---|---:|---|
| 자율 rollout 실패 원본 | 아니오 | failure bank, 실패 분포, 회귀 평가 |
| 조작자 실수 시연 | 아니오 | 수집 절차 개선 근거 |
| 센서·캘리브레이션 오류 실행 | 아니오 | 시스템 수정과 재시험 근거 |
| 실패 직전 사람이 복구한 HIL 구간 | 별도 데이터셋에서 가능 | recovery 학습, 원본 성공 시연과 분리 |
| 성공했지만 미끄러짐을 복구한 시연 | 기준에 따라 포함 | 복구 행동 분석, 조건 태그 필수 |
| 원인 미확정 실패 | 아니오 | `unresolved` failure bank |

실패가 많다고 곧바로 데이터를 더 모으지 않는다.

- 도착·TF·캘리브레이션·기구·서보 원인이면 시스템을 수정하고 같은 checkpoint 또는 같은
  PLANNED 산출물 버전으로 재시험한다.
- 관측 분포 밖의 초기 상태이면서 시스템 이상이 배제된 경우에만 성공 시연 또는 HIL 복구
  데이터를 보강한다.
- HIL 학습 포함 검증은 확인된 원인층 `policy_data`만 허용한다. navigation·hardware 등
  시스템 원인을 수집 결정 문자열만 바꿔 학습 보강으로 처리할 수 없다.
- 라벨 오류면 재라벨링하고 dataset version을 올린다.
- 실패 원본을 성공 시연 데이터에 섞어 실패 행동을 모방시키지 않는다.

`include_in_training=true`는 실패 원본의 허가가 아니라 검토한 HIL 파생 구간의 사용 결정이다.
복구 구간·제어 주체·성공 확인 근거와 별도 dataset ID를 기록해야 한다. `counterexample`은
실패를 분석하거나 평가할 때의 용도이며 BC의 목표 action으로 자동 편입하지 않는다.

HIL 파생 sidecar의 `training_provenance`에는 원본 전체 길이 `source_duration_s`, 원본 시간축의
사람 개입 구간 `source_intervention_time_range_s`, 그 안에서 추출한 `recovery_time_range_s`를
남긴다. 파생 `outcome.interventions`는 잘라낸 에피소드 시작을 0초로 하며 학습 구간 전체의
사람 제어를 기록한다. 실패 레코드의 `recovery_evidence_ids` 중에는 원본 시간축에서 복구
구간 전체를 포함하는 `time_range_s`가 있는 근거가 필요하다.
원인이 확정되고 HIL 수집 또는 재학습을 결정한 뒤, 담당자가 해당 근거에서 복구 성공을
확인해야 `recovery_verified_success=true`와 실제 제어 주체 `recovery_control_source`를
기록해 학습 포함할 수 있다. 이는 수정 후 동일 조건·회귀 검증인 `validation`과 별개다.
복구 시연으로 재학습하기 전에 문제가 이미 `resolved`일 것을 요구하지는 않는다.

`fill_class=TARGET`은 비전 추정량의 판정이다. 실측과 어긋난 false positive도 실패 데이터로
보존한다. 전체 성공을 주장하려면 최종 단계 결과·흘림 여부·실측 목표량도 성공과 일치해야 한다.

이미 분석·튜닝에 사용한 실패 조건은 회귀 평가에 재사용할 수 있지만, 처음 보는 조건의
일반화 성과라고 발표하지 않는다. 최종 holdout은 수집 전에 세션·장면 조건으로 분리하고,
원본과 그 원본에서 자른 모든 복구 구간은 같은 분할에 둔다. 파생 sidecar의
`training_provenance.source_split`을 필수 기록하고 최상위 `split`과 다르면 검증이 실패한다.
검증기는 두 선언의 일치만 검사한다. 원본 dataset의 실제 분할·영상의 성공 여부까지 조회하거나
판정하지 않으므로, 담당자는 원본 manifest와 근거를 대조한 후 승인한다.

에피소드 검증은 객체 ID 중복, 정책별 필수 역할(주방: cup/jug/shelf, 테이블: cup/shelf/table),
strategy와 phase backend의 일치, phase 시간·순서·시작 상태 출처, ACT checkpoint와 PLANNED
산출물 ID, `water_measurement.cup_id`의 실제 cup 객체 참조도 검사한다. `jsonschema`가 없으면 축소 검증만
수행하고 실패 레코드 참조 대조는 생략하며 종료 코드 3을 반환한다. 이를 검증 PASS로 취급하지 않는다.

## 6. 집계와 포트폴리오 증거

집계할 때 관측 코드와 확인 원인을 따로 센다.

- 단계별 `observed_code` 빈도
- `root_cause.layer`별 빈도와 미확정 비율
- 같은 원인이 발생한 조건 분포
- 조치 종류와 동일 조건 재시험 결과
- 재학습으로 해결된 실패와 시스템 수정으로 해결된 실패의 구분
- 수정 뒤 새로 생긴 회귀 실패

포트폴리오에는 성공 장면만 나열하지 않고, 대표 실패 한 건의 `관측 → 가설 → 기각 근거 →
확정 원인 → 수정 → 재시험`을 타임라인으로 보여준다. 실제 수치가 없는 예시 값은 성과로
사용하지 않는다.

## 7. 파일과 검사

- 실패 레코드 스키마: [`../schema/failure_record.schema.json`](../schema/failure_record.schema.json)
- 가상 작성 예시: [`../schema/example_failure_record.json`](../schema/example_failure_record.json)
- 에피소드 스키마: [`../schema/episode_metadata.schema.json`](../schema/episode_metadata.schema.json)
- 포함·제외 기준: [`../schema/에피소드_포함제외_기준.md`](../schema/에피소드_포함제외_기준.md)
- 수집 입력 예시: [`../schema/example_failure_capture.json`](../schema/example_failure_capture.json)
- 저장·집계 명령: [`../../tools/failure_bank.py`](../../tools/failure_bank.py)

```bash
cd ~/bimanual-robot
python3 tools/validate_failure_record.py
python3 tools/validate_failure_record.py /path/to/failure-record-directory
```

검증에는 `jsonschema`가 필요하다. 미설치로 전체 검증을 못 하는 경우 성공으로 처리하지
않는다. 필드 검사 PASS는 근거 영상의 진위나 로봇의 실제 성공을 증명하지 않는다.

## 8. 실제로 저장하고 사용하는 순서

### 8.1 관측 입력과 근거를 보존한다

수집 입력은 `failure_id`, `triage_owner`, `source`, `observation`, `context`,
`immediate_action` 여섯 필드다. `source`에 run ID·환경을, `observation`에 관측 단계·코드·
요약·판정 주체·심각도를 적는다. `context`에는 실행 당시의 scenario·strategy·phase backend·
코드·캘리브레이션·계측을 넣는다.
현재 PC의 Git HEAD를 실험 당시 commit으로 대신 기록하지 않는다. 모르는 값은 추정하지
않고 빈 매핑으로 남긴 뒤 분석 때 보강한다. `immediate_action`에는 실제 취한 조치만 적는다.

아래는 저장 형식을 확인하는 가상 예시다. 실영상이 아닌 예시 JSON을 근거로 복사하므로
성과나 실기체 시험 기록으로 사용하지 않는다.

```bash
cd ~/bimanual-robot
python3 tools/failure_bank.py capture \
  --input data/schema/example_failure_capture.json \
  --evidence data/schema/example_episode_meta.json \
  --root "$HOME/robot-artifacts/failures"
python3 tools/failure_bank.py verify-evidence "$HOME/robot-artifacts/failures"
python3 tools/failure_bank.py summary "$HOME/robot-artifacts/failures" --include-examples
```

실험에서는 입력을 실제 관측으로 바꾸고 `FAIL-YYYYMMDD-NNNN` ID와 실제 파일을 지정한다.
도구는 원본을 복사해 각 파일의 SHA-256을 기록하고 `open / untriaged / 학습 제외`로 시작한다.
같은 ID가 있으면 덮어쓰지 않는다. 복사 중 오류가 나면 부분 번들을 보존하며 마지막의
`failure.json`이 없는 번들을 완료로 취급하지 않는다. 기존 번들을 확인한 뒤 새 ID로
다시 수집한다. 이 명령은 로봇을 정지시키거나 Hub에 업로드하지 않는다.

### 8.2 원인·조치·재시험을 추가한다

보존한 `failure.json`에 가설과 evidence 참조를 추가한다. 반증된 가설도 삭제하지 않고
`rejected`와 기각 근거를 남긴다. 수정이 코드 변경이면 commit, 캘리브레이션 변경이면 새
calibration ID, 기구 변경이면 부품 버전과 계측 기록을 `response`에 연결한다.

원인이 확인된 상태(`confirmed`)와 수정이 검증된 상태(`resolved`)를 구분한다. 같은 조건
재시험과 다른 조건 회귀가 모두 PASS하고 protocol·판정 근거가 있어야 `resolved`로 닫는다.
run ID 목록만 적는 것으로 실험을 대신하지 않으며, 근거 파일에 각 run의 조건·strategy·
phase backend·checkpoint 또는 PLANNED 산출물·결과·사람 개입 여부와 전체 시도 수를 남긴다.
미실행은 `not_run`, 실패는 `fail`로 유지한다.

```bash
cd ~/bimanual-robot
python3 tools/validate_failure_record.py "$HOME/robot-artifacts/failures"
python3 tools/validate_episode_meta.py "$HOME/robot-artifacts/episode-meta" \
  --failure-record-dir "$HOME/robot-artifacts/failures"
python3 tools/failure_bank.py summary "$HOME/robot-artifacts/failures"
```

집계는 EXAMPLE ID를 기본 제외하고 환경·전략·phase·backend·관측 코드·확정 원인·재시험·
재학습 결정과 미분석/재시험 대기 ID를 출력한다. 중복 ID나 잘못된 레코드가 있으면 부분 집계를 성공으로
출력하지 않는다. 성공 실행의 분모가 없으므로 성공률은 `null`로 남긴다.

### 8.3 검증 뒤 팀에 공유한다

로컬 artifact 경로는 수집 PC의 임시 보관소다. 팀 공유가 승인된 데이터만 private Hub 또는
팀 artifact storage에 옮기고, `data/README.md` 인덱스에 실제 위치와 버전을 남긴다.
번들 내부의 상대 경로·SHA-256을 유지하면 다운로드 후 `verify-evidence`로 원본 일치를
확인할 수 있다. 서명 만료 URL이나 인증 토큰을 레코드에 넣지 않는다. 업로드 자동화와
영상/rosbag 구간 추출은 아직 이 도구의 구현 범위가 아니다.

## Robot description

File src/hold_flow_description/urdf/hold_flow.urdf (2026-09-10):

<?xml version="1.0" ?>
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
<robot name="hold_flow">
  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
  <link name="base_footprint"/>
  <link name="base_link">
    <inertial>
      <origin rpy="0 0 0" xyz="0 0 0.030"/>
      <mass value="0.250"/>
      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
    </inertial>
  </link>
  <joint name="base_footprint_joint" type="fixed">
    <parent link="base_footprint"/>
    <child link="base_link"/>
    <origin rpy="0 0 0" xyz="0 0 0.0329"/>
  </joint>
  <link name="chassis_bottom_link">
    <inertial>
      <origin rpy="0 0 0" xyz="0 0 0.024"/>
      <mass value="0.4"/>
      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
    </inertial>
    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
  </link>
  <joint name="chassis_bottom_link_joint" type="fixed">
    <parent link="base_link"/>
    <child link="chassis_bottom_link"/>
    <origin rpy="0 0 0" xyz="0 0 -0.0269"/>
  </joint>
  <link name="chassis_middle_link">
    <inertial>
      <origin rpy="0 0 0" xyz="0 0 0.003"/>
      <mass value="0.34"/>
      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
    </inertial>
    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
  </link>
  <joint name="chassis_middle_link_joint" type="fixed">
    <parent link="base_link"/>
    <child link="chassis_middle_link"/>
    <origin rpy="0 0 0" xyz="0 0 0.0291"/>
  </joint>
  <link name="chassis_top_link">
    <inertial>
      <origin rpy="0 0 0" xyz="0 0 0.004"/>
      <mass value="0.424"/>
      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
    </inertial>
    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
  </link>
  <joint name="chassis_top_link_joint" type="fixed">
    <parent link="base_link"/>
    <child link="chassis_top_link"/>
    <origin rpy="0 0 0" xyz="0 0 0.6791"/>
  </joint>
  <link name="front_left_frame_column_link">
    <inertial>
      <origin rpy="0 0 0" xyz="0 0 0.322"/>
      <mass value="0.29"/>
      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
    </inertial>
    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
  </link>
  <joint name="front_left_frame_column_link_joint" type="fixed">
    <parent link="base_link"/>
    <child link="front_left_frame_column_link"/>
    <origin rpy="0 0 0" xyz="0.130 0.130 0.0351"/>
  </joint>
  <link name="front_right_frame_column_link">
    <inertial>
      <origin rpy="0 0 0" xyz="0 0 0.322"/>
      <mass value="0.29"/>
      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
    </inertial>
    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
  </link>
  <joint name="front_right_frame_column_link_joint" type="fixed">
    <parent link="base_link"/>
    <child link="front_right_frame_column_link"/>
    <origin rpy="0 0 0" xyz="0.130 -0.130 0.0351"/>
  </joint>
  <link name="rear_left_frame_column_link">
    <inertial>
      <origin rpy="0 0 0" xyz="0 0 0.322"/>
      <mass value="0.29"/>
      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
    </inertial>
    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
  </link>
  <joint name="rear_left_frame_column_link_joint" type="fixed">
    <parent link="base_link"/>
    <child link="rear_left_frame_column_link"/>
    <origin rpy="0 0 0" xyz="-0.130 0.130 0.0351"/>
  </joint>
  <link name="rear_right_frame_column_link">
    <inertial>
      <origin rpy="0 0 0" xyz="0 0 0.322"/>
      <mass value="0.29"/>
      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
    </inertial>
    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
  </link>
  <joint name="rear_right_frame_column_link_joint" type="fixed">
    <parent link="base_link"/>
    <child link="rear_right_frame_column_link"/>
    <origin rpy="0 0 0" xyz="-0.130 -0.130 0.0351"/>
  </joint>
  <link name="left_arm_backing_link">
    <inertial>
      <origin rpy="0 0 0" xyz="0 0 0.003"/>
      <mass value="0.058"/>
      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
    </inertial>
    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
  </link>
  <joint name="left_arm_backing_link_joint" type="fixed">
    <parent link="base_link"/>
    <child link="left_arm_backing_link"/>
    <origin rpy="0 0 0" xyz="0 0.075 0.6871"/>
  </joint>
  <link name="right_arm_backing_link">
    <inertial>
      <origin rpy="0 0 0" xyz="0 0 0.003"/>
      <mass value="0.058"/>
      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
    </inertial>
    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
  </link>
  <joint name="right_arm_backing_link_joint" type="fixed">
    <parent link="base_link"/>
    <child link="right_arm_backing_link"/>
    <origin rpy="0 0 0" xyz="0 -0.075 0.6871"/>
  </joint>
  <link name="camera_backing_link">
    <inertial>
      <origin rpy="0 0 0" xyz="0 0 0.004"/>
      <mass value="0.03"/>
      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
    </inertial>
    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
  </link>
  <joint name="camera_backing_link_joint" type="fixed">
    <parent link="base_link"/>
    <child link="camera_backing_link"/>
    <origin rpy="0 0 0" xyz="-0.120 0 0.6871"/>
  </joint>
  <link name="lidar_riser_link">
    <inertial>
      <origin rpy="0 0 0" xyz="0 0 0.04"/>
      <mass value="0.274"/>
      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
    </inertial>
    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
  </link>
  <joint name="lidar_riser_link_joint" type="fixed">
    <parent link="base_link"/>
    <child link="lidar_riser_link"/>
    <origin rpy="0 0 0" xyz="0.100 0 0.0351"/>
  </joint>
  <link name="battery_link">
    <inertial>
      <mass value="0.55"/>
      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
    </inertial>
    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
  </link>
  <joint name="battery_link_joint" type="fixed">
    <parent link="base_link"/>
    <child link="battery_link"/>
    <origin rpy="0 0 0" xyz="-0.040 0 0.0071"/>
  </joint>
  <link name="electronics_link">
    <inertial>
      <mass value="0.35"/>
      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
    </inertial>
    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
  </link>
  <joint name="electronics_link_joint" type="fixed">
    <parent link="base_link"/>
    <child link="electronics_link"/>
    <origin rpy="0 0 0" xyz="0.030 0 0.0571"/>
  </joint>
  <link name="left_wheel_link">
    <inertial>
      <mass value="0.11"/>
      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
    </inertial>
    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
  </link>
  <joint name="left_wheel_joint" type="continuous">
    <parent link="base_link"/>
    <child link="left_wheel_link"/>
    <origin rpy="0 0 0" xyz="0 0.160 0"/>
    <axis xyz="0 1 0"/>
    <limit effort="0.981" velocity="4.72"/>
    <dynamics damping="0.02" friction="0.02"/>
  </joint>
  <link name="right_wheel_link">
    <inertial>
      <mass value="0.11"/>
      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
    </inertial>
    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
  </link>
  <joint name="right_wheel_joint" type="continuous">
    <parent link="base_link"/>
    <child link="right_wheel_link"/>
    <origin rpy="0 0 0" xyz="0 -0.160 0"/>
    <axis xyz="0 1 0"/>
    <limit effort="0.981" velocity="4.72"/>
    <dynamics damping="0.02" friction="0.02"/>
  </joint>
  <link name="front_caster_link">
    <inertial>
      <mass value="0.060"/>
      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
    </inertial>
    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
  </link>
  <joint name="front_caster_joint" type="fixed">
    <parent link="base_link"/>
    <child link="front_caster_link"/>
    <origin rpy="0 0 0" xyz="0.12 0 -0.0204"/>
  </joint>
  <link name="rear_caster_link">
    <inertial>
      <mass value="0.060"/>
      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
    </inertial>
    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
  </link>
  <joint name="rear_caster_joint" type="fixed">
    <parent link="base_link"/>
    <child link="rear_caster_link"/>
    <origin rpy="0 0 0" xyz="-0.12 0 -0.0204"/>
  </joint>
  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
  <link name="camera_mast_link">
    <inertial>
      <origin rpy="0 0 0" xyz="0 0 0.12"/>
      <mass value="0.044"/>
      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
    </inertial>
    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
  </link>
  <joint name="camera_mast_joint" type="fixed">
    <parent link="base_link"/>
    <child link="camera_mast_link"/>
    <origin rpy="0 0 0" xyz="-0.120 0 0.6951"/>
  </joint>
  <link name="camera_link">
    <inertial>
      <mass value="0.310"/>
      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
    </inertial>
    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
  </link>
  <joint name="camera_mount_joint" type="fixed">
    <parent link="camera_mast_link"/>
    <child link="camera_link"/>
    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
    <origin rpy="0 0.6108652382 0" xyz="-0.006383 0 0.253472"/>
  </joint>
  <link name="camera_cradle_link">
    <inertial>
      <origin rpy="0 0 0" xyz="0 0 0.015"/>
      <mass value="0.085"/>
      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
    </inertial>
    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
  </link>
  <joint name="camera_cradle_joint" type="fixed">
    <parent link="camera_link"/>
    <child link="camera_cradle_link"/>
    <origin rpy="0 0 0" xyz="0 0 -0.030"/>
  </joint>
  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
  <link name="camera_depth_optical_frame"/>
  <joint name="camera_depth_optical_joint" type="fixed">
    <parent link="camera_link"/>
    <child link="camera_depth_optical_frame"/>
    <origin rpy="-1.5707963268 0 -1.5707963268" xyz="0.020 0 0"/>
  </joint>
  <link name="camera_color_optical_frame"/>
  <joint name="camera_color_optical_joint" type="fixed">
    <parent link="camera_depth_optical_frame"/>
    <child link="camera_color_optical_frame"/>
    <origin rpy="0 0 0" xyz="0 0 0"/>
  </joint>
  <link name="laser_link">
    <inertial>
      <mass value="0.042"/>
      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
    </inertial>
    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
  </link>
  <joint name="laser_joint" type="fixed">
    <parent link="base_link"/>
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

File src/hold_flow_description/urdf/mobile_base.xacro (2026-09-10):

<?xml version="1.0"?>
<robot xmlns:xacro="http://www.ros.org/wiki/xacro">
  <xacro:macro name="box_inertial" params="mass x y z">
    <inertial>
      <origin xyz="0 0 ${z / 2.0}" rpy="0 0 0"/>
      <mass value="${mass}"/>
      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
    </inertial>
  </xacro:macro>

  <xacro:macro name="wheel_inertial" params="mass radius width">
    <inertial>
      <mass value="${mass}"/>
      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
    </inertial>
  </xacro:macro>

  <xacro:macro name="primitive_box_link" params="name parent xyz mass sx sy sz material">
    <link name="${name}">
      <inertial>
        <mass value="${mass}"/>
        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
      </inertial>
      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
    </link>
    <joint name="${name}_joint" type="fixed">
      <parent link="${parent}"/><child link="${name}"/><origin xyz="${xyz}" rpy="0 0 0"/>
    </joint>
  </xacro:macro>

  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
  <xacro:macro name="cad_mesh_link" params="name parent xyz mesh mass sx sy sz material">
    <link name="${name}">
      <xacro:box_inertial mass="${mass}" x="${sx}" y="${sy}" z="${sz}"/>
      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
    </link>
    <joint name="${name}_joint" type="fixed">
      <parent link="${parent}"/>
      <child link="${name}"/>
      <origin xyz="${xyz}" rpy="0 0 0"/>
    </joint>
  </xacro:macro>

  <xacro:macro name="hold_flow_mobile_base">
    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
    <link name="base_footprint"/>
    <link name="base_link">
      <inertial>
        <origin xyz="0 0 0.030" rpy="0 0 0"/>
        <mass value="0.250"/>
        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
      </inertial>
    </link>
    <joint name="base_footprint_joint" type="fixed">
      <parent link="base_footprint"/>
      <child link="base_link"/>
      <origin xyz="0 0 0.0329" rpy="0 0 0"/>
    </joint>

    <xacro:cad_mesh_link name="chassis_bottom_link" parent="base_link" xyz="0 0 -0.0269" mesh="chassis_bottom.stl" mass="0.400" sx="0.300" sy="0.300" sz="0.048" material="hold_flow_dark"/>
    <xacro:cad_mesh_link name="chassis_middle_link" parent="base_link" xyz="0 0 0.0291" mesh="chassis_middle.stl" mass="0.340" sx="0.300" sy="0.300" sz="0.006" material="hold_flow_white"/>
    <xacro:cad_mesh_link name="chassis_top_link" parent="base_link" xyz="0 0 0.6791" mesh="chassis_top.stl" mass="0.424" sx="0.300" sy="0.300" sz="0.008" material="hold_flow_white"/>

    <xacro:cad_mesh_link name="front_left_frame_column_link" parent="base_link" xyz="0.130 0.130 0.0351" mesh="frame_column.stl" mass="0.290" sx="0.020" sy="0.020" sz="0.644" material="silver"/>
    <xacro:cad_mesh_link name="front_right_frame_column_link" parent="base_link" xyz="0.130 -0.130 0.0351" mesh="frame_column.stl" mass="0.290" sx="0.020" sy="0.020" sz="0.644" material="silver"/>
    <xacro:cad_mesh_link name="rear_left_frame_column_link" parent="base_link" xyz="-0.130 0.130 0.0351" mesh="frame_column.stl" mass="0.290" sx="0.020" sy="0.020" sz="0.644" material="silver"/>
    <xacro:cad_mesh_link name="rear_right_frame_column_link" parent="base_link" xyz="-0.130 -0.130 0.0351" mesh="frame_column.stl" mass="0.290" sx="0.020" sy="0.020" sz="0.644" material="silver"/>

    <xacro:cad_mesh_link name="left_arm_backing_link" parent="base_link" xyz="0 0.075 0.6871" mesh="arm_adapter.stl" mass="0.058" sx="0.130" sy="0.070" sz="0.006" material="hold_flow_dark"/>
    <xacro:cad_mesh_link name="right_arm_backing_link" parent="base_link" xyz="0 -0.075 0.6871" mesh="arm_adapter.stl" mass="0.058" sx="0.130" sy="0.070" sz="0.006" material="hold_flow_dark"/>
    <xacro:cad_mesh_link name="camera_backing_link" parent="base_link" xyz="-0.120 0 0.6871" mesh="camera_backing.stl" mass="0.030" sx="0.055" sy="0.055" sz="0.008" material="hold_flow_dark"/>
    <xacro:cad_mesh_link name="lidar_riser_link" parent="base_link" xyz="0.100 0 0.0351" mesh="lidar_riser.stl" mass="0.274" sx="0.065" sy="0.050" sz="0.080" material="hold_flow_dark"/>
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

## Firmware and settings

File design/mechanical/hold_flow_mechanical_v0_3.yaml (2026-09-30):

schema_version: "0.3"
design_id: hold_flow_mechanical_v0_3
status: simulation_model_ready_physical_measurements_pending
revision: 2026-09-22_left_stock_so101_gripper_selected
units:
  length: mm
  mass: kg
  angle: deg
  torque: N_m

coordinate_convention:
  x: forward
  y: left
  z: up
  base_footprint_origin: chassis_center_on_floor
  note: 모든 xyz는 별도 parent가 없으면 base_footprint 기준

provenance:
  tabletop_height:
    selected_design_datum: 720.0
    evidence: 710_to_865_mm_accessible_work_surface_range
    source: https://www.access-board.gov/ada/ada-ibc-comparison/chapter-9/
    confidence: design_assumption_not_measured_average
  so101:
    source: https://github.com/TheRobotStudio/SO-ARM100
    checked_commit: eecbe3e0a9ebb23e25ad7b2759b03884c6660903
    upstream_urdf: Simulation/SO101/so101_new_calib.urdf
    upstream_urdf_sha256: 3a65d2d35e68a8d2f0c2cc176d19b884506543c93ba72980145b80abe276022c
    license: Apache-2.0
    local_kinematic_source: calibrated_JD_AMR_SO101_URDF
    local_source_sha256: d80275f4b4313229001a55836529fdf2747917bb49fc6c8490195ff42f0d7634
  right_parallel_gripper:
    source: https://github.com/ggao50/SO101-Parallel-Gripper
    checked_commit: b0614b72c62e3891b1f7faa8b06c6eb3d490a9c2
    upstream_license_status: no_license_file_found_on_2026_09_08
    redistribution_policy: do_not_vendor_upstream_meshes_use_project_authored_proxy
  left_finray_fingers_historical:
    local_selection_manifest: design/gripper/finray_80mm_lip3_selection.yaml
    source_file_sha256: 93d2fd90adc2b6b045f3cca8f153ed68d5431e301bcc370924c75d72f82b6373
    upstream_source_status: exact_url_not_recorded
    upstream_license_status: not_verified
    redistribution_policy: do_not_vendor_mesh_or_gcode_until_license_is_verified
    current_build_use: false
    superseded_date: 2026-09-22
    superseded_by: stock_so101_rotating_jaw

chassis:
  # 실제 하부 프로파일 외곽은 폭(y) 450 mm × 전후(x) 340 mm다.
  frame_outer_footprint: [340.0, 450.0]
  tabletop_footprint: [340.0, 450.0]
  corner_radius: 12.0
  plates:
    bottom:
      z_bottom: 6.0
      thickness: 6.0
      fabrication: printed_or_cut_plate_candidate
    middle:
      z_bottom: 62.0
      thickness: 6.0
      fabrication: printed_or_cut_plate_candidate
    tabletop:
      z_bottom: 714.0
      thickness: 6.0
      z_top: 720.0
      fabrication: four_piece_fdm_petg
      split_x: -50.0
      seam_gap: 0.6
      quadrant_names: [front_left, front_right, rear_left, rear_right]
      material_for_simulation: PETG_nominal_20pct_infill
      simulation_mass_each: 0.170
      support_profiles: perimeter_plus_split_crossmembers
  k1_max:
    nominal_build_volume: [300.0, 300.0, 300.0]
    one_piece_tabletop_safe_to_print: false
    four_piece_tabletop_safe_to_print: true
    reason: 340x450mm assembly is divided into 220x224.7mm and 119.7x224.7mm panels
  vertical_frame:
    type: four_2020_extrusion_candidates
    centers_xy:
      - [150.0, 205.0]
      - [150.0, -205.0]
      - [-150.0, 205.0]
      - [-150.0, -205.0]
    section: [20.0, 20.0]
    z_bottom: 60.0
    z_top: 694.0
    length: 634.0
    nominal_mass_each: 0.304
    mass_status: replace_with_selected_extrusion_catalog_or_measured_value
  profile_rings:
    section: [20.0, 20.0]
    lower_center_z: 50.0
    upper_center_z: 704.0
    x_rail_length: 300.0
    y_rail_length: 450.0
    x_rail_center_y: 215.0
    y_rail_center_x: 160.0
    center_crossmembers: true
    nominal_linear_mass_kg_m: 0.48

printed_mounts:
  battery_plate:
    origin_xyz: [-40.0, 0.0, 68.0]
    footprint: [180.0, 120.0]
    thickness: 6.0
    simulation_mass: 0.120
    fabrication: FDM_PETG_flat_no_support
  lidar_plate:
    origin_xyz: [100.0, 0.0, 145.0]
    footprint: [90.0, 75.0]
    thickness: 3.0
    simulation_mass: 0.035
    fabrication: FDM_PETG_flat_no_support
    support_note: lower-frame standoffs are provisional until LDS-03 hole pattern is measured

internal_payloads:
  battery:
    center_xyz: [-40.0, 0.0, 94.0]
    envelope: [140.0, 80.0, 40.0]
    simulation_mass: 0.550
    status: candidate_not_selected
  electronics:
    center_xyz: [30.0, 0.0, 90.0]
    envelope: [160.0, 120.0, 40.0]
    simulation_mass: 0.350
    status: distributed_lumped_proxy
  wiring_fasteners_allowance:
    simulation_mass: 0.250
    status: distributed_lumped_into_base_link

arm_mounts:
  source_base_envelope: [110.93, 72.0, 87.0]
  adapter:
    footprint: [130.0, 70.0]
    thickness: 6.0
    fabrication: printed_petg_candidate
  left:
    xyz: [20.0, 170.0, 726.0]
    rpy: [0.0, 0.0, 0.0]
    gripper: stock_so101_rotating_jaw_without_tpu_attachment
  right:
    xyz: [20.0, -170.0, 726.0]
    rpy: [0.0, 0.0, 0.0]
    gripper: ggao50_parallel_gripper_project_proxy
  center_spacing: 340.0
  front_edge_distance: 150.0
  side_margin: 19.0
  adapter_edge_margin: 20.0
  center_gap: 268.0
  mount_hole_pattern_status: physical_measurement_required
  servo_variant_status: physical_label_check_required

left_cup_gripper:
  p0_actuator: stock_so101_rotating_jaw
  selected_attachment: null
  selected_geometry: upstream_stock_so101_rotating_jaw
  material: upstream_stock_print_material_not_verified
  retention: stock_jaw_contact_only
  status: selected_for_current_build_ik_physical_cup_tests_pending
  superseded_candidates:
    - finray_80mm_lip3_reinforced_pair
    - independent_strap_mount_concave_jaw_overcaps
  calibration_status: repository_calibration_confirmed_current_by_user_20260929
  measurement_gates:
    - stock_jaw_mount_and_full_open_close_clearance
    - reuse_current_repository_calibration_without_automatic_recalibration
    - actual_cup_outer_diameter_and_taper
    - wet_surface_retention_and_slip_test

right_parallel_gripper:
  model: ggao50_SO101_Parallel_Gripper
  opening_max_published: 105.0
  reach_published: 72.0
  mass_published: 0.165
  urdf_proxy_mass: 0.159
  mass_status: published_value_is_approximate_proxy_is_nominal_until_weighed
  urdf_geometry: project_authored_dimensional_proxy
  contact_surface: upstream_flat_jaws_without_groove_or_replaceable_insert
  selected_insert: none
  jaw_modification: none
  proxy_scope: rail_connector_racks_and_unmodified_flat_jaws
  exact_mesh_gate: author_license_permission_or_user_local_nonredistributed_asset
  simulation_joint:
    type: dual_prismatic_mimic
    primary_stroke: [10.0, 43.3]
    effort: 40.0
    velocity: 50.0

camera:
  model: Orbbec_Astra_S
  design_envelope: [40.0, 165.0, 48.0]
  mass: 0.310
  optical_center_xyz: [-110.0, 0.0, 970.0]
  height_above_tabletop: 250.0
  pitch_down: 35.0
  depth_range: [400.0, 2000.0]
  depth_fov_hv: [58.4, 45.5]
  interface: USB_2_0
  mount:
    mast_center_xy: [-120.0, 0.0]
    mast_section: [20.0, 20.0]
    mast_z_bottom: 728.0
    mast_length: 240.0
    backing_footprint: [55.0, 55.0]
    backing_thickness: 8.0
    body_center_xyz: [-126.383, 0.0, 981.472]
  physical_measurement_gates:
    - actual_optical_center_from_mount
    - selected_camera_serial_intrinsics
    - wrist_and_gripper_occlusion_map

navigation:
  drive_type: differential_two_wheel_two_ball_caster
  reuse_source:
    repository: https://github.com/mmporong/jdamr_cube_ros
    checked_commit: 82fa87a257080bd2298bada2b11d60f686c555f1
    firmware: firmware/jdamr_cube_fw/jdamr_cube_fw.ino
    motor: Feetech_STS3215_C018_12V
    bus_baud: 1000000
    left_servo_id: 2
    right_servo_id: 1
    host_parameter_source: jdamr_cube_bringup/launch/real_bringup.launch.py
    old_effective_wheel_separation_mm: 183.6
    reuse_decision: hardware_reusable_ros_geometry_and_direction_check_required
  wheel:
    measured_diameter: 65.0
    calibrated_effective_radius: 32.9
    center_xyz_left: [0.0, 160.0, 32.9]
    center_xyz_right: [0.0, -160.0, 32.9]
    geometric_center_separation: 320.0
    effective_separation_status: calibrate_on_physical_chassis
    mass_each: 0.110
    joint_effort: 0.981
    joint_velocity: 4.72
    initial_host_parameters:
      wheel_radius_m: 0.0329
      wheel_separation_m: 0.320
      counts_per_rev: 4096
      note: wheel_separation 0.320 m는 기하 시작값이며 직진·제자리 회전으로 유효값을 재보정
  ball_casters:
    ball_radius: 12.5
    mass_each: 0.060
    centers_xyz:
      - [120.0, 0.0, 12.5]
      - [-120.0, 0.0, 12.5]
    joint_model: fixed_sphere_contact_proxy
    physics_limit: urdf_cannot_model_free_rolling_ball_spin_axes
    isaac_tuning: assign_low_friction_contact_material_after_import
  support_polygon_xy:
    - [120.0, 0.0]
    - [0.0, 160.0]
    - [-120.0, 0.0]
    - [0.0, -160.0]
  lidar_candidate:
    model: ROBOTIS_LDS_03
    center_xyz: [100.0, 0.0, 165.0]
    envelope: [54.7, 39.7, 34.0]
    mass: 0.042
    status: selected_p0_scan_plane_and_occlusion_measurement_required
    mount_riser:
      footprint: [90.0, 75.0]
      height: 3.0
      z_bottom: 145.0
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

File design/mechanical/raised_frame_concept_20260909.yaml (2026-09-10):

status: preliminary_trade_study_not_build_release
units: SI
provenance:
  base: docs/20260909_하단프레임_실물치수_모델링기록.md
  target_height: 0.720 m, previous design datum; actual table measurement pending
  profile_2020: https://cdn.item24.com/product-assets/DOK_PROD_37015_%23SEN_%23AIN_%23V1.pdf
  profile_2040: https://th.misumi-ec.com/en/vona2/detail/110302684350/
  aluminum_modulus: https://www.aluminum.org/sites/default/files/2021-11/103.1_Aluminum_EPD_HotRolledAluminum.pdf
  servo_12v_candidate: https://www.feetechrc.com/525603.html
  arms: previous URDF nominal inertial masses, not weighed
  mass_and_load_cases: engineering assumptions for sensitivity study, not measurements
geometry:
  deck_height: 0.720
  deck_thickness: 0.002
  reference_flat_deck_thickness: 0.004
  lower_frame_top: 0.060
  lower_crossmember_height: 0.020
  upper_ring_height: 0.020
  tower_width: 0.260
  upper_profile_total_length: 1.520
  support_front_x: 0.110
  support_rear_x: -0.110
  rear_contact_half_width: 0.215
  wheel_outer_half_width: 0.270
  assumed_wheel_width: 0.030
  wheel_radius: 0.035
  camera_center_height_above_deck_candidates: [0.380, 0.540]
  recommended_camera_center_height_above_deck: 0.540
  recommended_camera_pitch_down_degrees: 43.0
materials:
  E_aluminum: 69000000000.0
  I_2020: 0.0000000072
  I_2040_weak: 0.00000001358
  I_2040_strong: 0.0000000513
  density_aluminum: 2700.0
  E_steel: 200000000000.0
  density_steel: 7850.0
  profile_2020_kg_per_m: 0.48
  strap_width: 0.020
  strap_thickness: 0.0015
weight_optimization:
  folded_deck_skin_thickness: 0.002
  folded_deck_flange_mass_allowance: 0.130
  brace_material: aluminum
  note: 절곡 판과 알루미늄 인장재 후보; 체결부 시험 전
screening:
  g: 9.80665
  lateral_force: 20.0
  upper_applied_moment: 8.0
  effective_top_mass: 4.0
  ideal_to_joint_stiffness_fractions: [1.0, 0.1, 0.01]
  acceleration_cases: [0.20, 0.50, 1.0]
  slope_degrees: [0.0, 3.0, 5.0]
  rolling_coefficient_cases: [0.02, 0.05, 0.10]
  tire_friction_assumption: 0.5
  screening_margin_target: 0.030
  service_speed_candidate: 0.080
  rated_torque_candidate: 0.980665
  no_load_rpm_candidate: 45.0
  step_height_cases: [0.002, 0.005, 0.010]
mass_assumptions:
  drive_and_casters: {mass: 0.50, x: 0.0, z: 0.035}
  brackets_wiring: {mass: 0.50, x: 0.0, z: 0.30}
  battery: {mass: 0.80, x: -0.04, z: 0.12}
  boards_pi: {mass: 0.35, x: -0.04, z: 0.15}
  lower_tray: {mass: 0.25, x: 0.0, z: 0.12}
  camera_mast: {mass: 0.40, x: -0.12, z: 0.90, basis: legacy_250mm_camera_height_screening_budget_not_current_540mm_design}
  lidar_mount: {mass: 0.08, x: 0.19, z: 0.20}
  left_arm: {mass: 0.690006, x: 0.0, z: 0.82}
  right_arm: {mass: 0.837006, x: 0.0, z: 0.82}
poses:
  parked: {arm_com_x: 0.02, arm_com_z: 0.82, left_payload: 0.0, right_payload: 0.0, payload_x: 0.0}
  transport_cup_shelf_assumption: {arm_com_x: 0.02, arm_com_z: 0.82, left_payload: 0.30, right_payload: 0.0, payload_x: 0.0, payload_y_half: 0.0, payload_z: 0.65}
  legacy_light: {arm_com_x: 0.16, arm_com_z: 0.80, left_payload: 0.12, right_payload: 0.12, payload_x: 0.35}
  serving_example: {arm_com_x: 0.16, arm_com_z: 0.80, left_payload: 0.30, right_payload: 0.56, payload_x: 0.35}
  heavy_pitcher: {arm_com_x: 0.16, arm_com_z: 0.80, left_payload: 0.30, right_payload: 1.10, payload_x: 0.35}

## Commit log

2026-08-19 docs(kickoff): 양팔 로봇 팀 프로젝트 리포 개설 및 킥오프 기록
    - 킥오프 회의 원본 보존 + 결정사항·액션아이템 실행용 정리본 분리
    - 담당 파트(로봇 제어 IK+Depth, 이미테이션 러닝) 팀 제출용 문서 초안
    - 리서치 계획 R1~R4, 판정 질문 기준으로 완료 판정
    - 데이터 저장 규격: LeRobot v3.0 고정, 수집 조건 메타데이터 스키마,
    에피소드 포함/제외 기준 8종, dataset card 템플릿
    - 메타데이터 검증 도구 작성 (정상 통과·고의 오류 5건 검출 확인)
2026-08-19 docs(research): R4·R5 양팔 회사·태스크 조사와 포트폴리오 유효성 판정
    - 국내 공고 실측 389건에서 양팔·매니퓰레이션·모방학습 셀 재집계
    - 양팔 SW 직무는 신입 불가(경력 6년↑·석사↑), 데이터 파이프라인 층은 신입 개방
    - 픽앤플레이스는 B0라 양팔 근거가 못 됨, B2는 peg-insertion·천 접기·조립
    - 후보 태스크 7개 6축 채점 → 수집 파이프라인·IK 대 IL 비교를 주 산출물로
    - N2 흡수안 채택, 무게 제외 판정은 유지하고 관측만 기록
2026-08-19 docs(research): R1 양팔 동시 텔레옵 확정, R6 실행 설계
    - LeRobot이 양팔 공식 지원 확인 (bi_so_follower·bi_so_leader·BimanualMixin)
    - 조작자 1명이 양손으로 리더암 2대, 협응 태스크 제약 해제
    - 좌우 표현 규약 확정: left_/right_ 접두어 방식, 본수집 보류 해제
    - HIL 개입 수집(DAgger 계열)이 bi_so_leader 지원 — 3단계 카드로 채택
    - RoboTwin 2.0 태스크 50종·표준 평가 프로토콜 확보
    - 3단계 누적 설계와 M03~M07 커리큘럼 정합표 작성
2026-08-20 docs(research): R7 해외 양팔 로봇 회사와 실배치 사례 조사
    - 양팔 필요 근거를 세 갈래로 분류: 무게·부피 / 고정+작업 / 사람 작업장
    - Dexterity Mech FedEx 실배치(두 팔 59kg), ABB YuMi 소형 조립·실험실
    - 휴머노이드 3사 실배치는 아직 옮기기·키팅 범주
    - Mobile ALOHA 태스크 카탈로그, 시연 50회 80% 기준선 재확인
    - 간이 버전 후보 4종에 원본 회사와 양팔 근거 부착
2026-08-20 docs(research): R8 하드웨어 제약 역산으로 태스크 확정
    - SO-101 실측 사양: 리치 346mm, 5축+그리퍼, STS3215 16.5kg·cm
    - wrist_roll이 full_turn_motor — 회전 개폐가 하드웨어 지원 동작
    - 무게 근거(Dexterity형) 후보 탈락, 고정+작업 형태만 생존
    - 권고: 용기 개폐 작업 셀 (반작용 토크가 양팔 필수 근거)
    - 단팔 대조군을 귀무 대조로 설계, 난이도 L1~L4 분할
2026-08-20 docs(project): 프로젝트 정의 확정 — 데스크톱 시료 취급 셀
    - 원본 ABB YuMi 실험실 워크스테이션의 테이블탑 축소판
    - 양팔 근거는 회전 반작용 토크, 하드웨어의 wrist_roll 전회전 활용
    - 태스크 계단 T1~T4를 같은 파이프라인·프로토콜로 검증
    - 단팔 대조군·귀무 정책·실패 유형 5종을 측정 골격으로
    - 수집량 200 에피소드 5~8시간 산출, 일정 내 실현성 확인
    - 축소 우선순위 명시: 대조군과 실패 분류는 마지막까지 유지
2026-08-20 docs(research): R9 석션 엔드이펙터 검토와 현황 요약
    - 석션은 회전 토크 전달 불가 — 뚜껑 개폐와 상충함을 명시
    - SO-101 그리퍼 닫힘 15초 실측이 석션 검토의 실질 근거
    - 구성 3종 비교: 그리퍼2 / 석션2 / 석션1+그리퍼1(비대칭)
    - 권고는 절충안 — A로 관통 후 C로 확장, 구성 비교를 축으로
    - 현황 요약 한 장 작성, PROGRESS 4차 엔트리
2026-08-20 docs(research): R10 태스크 재아이데이션 — 와이어 하네스 제안
    - 뚜껑은 강체라 규칙으로 풀 수 있어 학습 필요성이 약함
    - 유연물 난이도 계층 1D(케이블) < 2D(천·비닐) < 3D(반죽)
    - 와이어 하네스는 자동차 전장 자동화 미해결 영역, 지금도 수작업
    - 양팔+동적 조작이 현재 연구 주류(엉킴 분리 91.2% 보고)
    - 회전 토크 불필요·저페이로드로 하드웨어 제약 전부 통과
    - T1~T4 설계와 케이블용 실패 유형 F1~F5 재정의
2026-08-20 docs(research): R11 태스크 후보 7종 비교
    - 평가 축: 양팔 필수성 · 학습 필수성 · 산업 근거 · 하드웨어 · 판정
    - 1위 보호필름 박리 — 테솔로(국내, R4 실측 공고) DG-4F 솔루션 직결
    - 2위 와이어 하네스 라우팅 — 90% 수작업, 하드웨어 궁합 최상
    - 케이블 타이는 인체공학 근거(작업자 부담 최다 공정)
    - 스냅핏·종이분리는 학습 또는 양팔 근거 부족으로 하위
2026-08-20 docs(research): R12 아이데이션 2차 — 서비스·리테일·순환경제 축 7종
    - stabilizing arm / acting arm 역할 분리가 학계 정립 용어임을 확인
    - Apple Daisy(시간당 200대 분해), 신발 산업 양팔 포장 논문 실재
    - Telexistence는 자율 98%+VR 원격개입 — HIL 구조의 상용 근거
    - 1위 모종 이식(아이오크롭스 연결, HW 최적), 2위 전자제품 분해
    - 선반 진열은 태스크로는 B0라 부적합, 아키텍처 근거로만 인용
2026-08-20 docs(research): R13 양팔 조작 논문 10편 정리
    - 선정 기준은 유명세가 아니라 우리 프로젝트에서의 활용처
    - MEVION은 SO-101·ALOHA·OpenArm 8축 비교 — 우리 하드웨어가 표 안에 있음
    - DexMimicGen은 소수 시연 자동 증강 — 수집량·일정 리스크 완충
    - VoxAct-B의 acting/stabilizing 역할 분리를 용어로 채택
    - 케이블 축 4편(실패복구·텔레옵보조·라우팅 프리미티브·DLO-Lab)
    - 부록에 후순위 8편과 제외 사유 병기
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2026-09-03 feat(robot): 출력용 CAD와 양팔 URDF P0 추가
    [arm_adapter.step, arm_adapter.stl, astra_cradle.step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]
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2026-09-03 feat(cad): M1 공차 쿠폰 모델과 K1 Max PETG 슬라이싱 경로 추가
    인계 문서 출력 순서 1번인 M1 공차 쿠폰에 모델이 없어 실행할 수 없던 문제를
    해결한다. 6절 M1 표를 그대로 형상으로 옮긴 쿠폰 5종을 생성하고, 5.2절 시작
    프로파일을 적용하는 슬라이싱 경로를 함께 넣는다.
    - generate_m1_coupons.py: M3/M4 여유홀, 6 mm 로드, M3 인서트 블라인드홀,
    면당 유격 4종 소켓과 기준 각기둥, 마스트·이음관 시험편. 전부 수직 프리즘이라
    45° 기준 서포트 불필요, 각인은 윗면을 파 내려간다
    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
    [coupon_m1_coupler_stub.step, coupon_m1_coupler_stub.stl, coupon_m1_fit_plug.step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]
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2026-09-03 feat(gripper): ggao50 죠용 볼트 체결 파지 인서트 3종 추가
    ggao50 죠의 파지면은 완전 평면이라(축정렬 평면 면적비 69%) 원통인 병이
    죠 안에서 돌고 기울일 때 축방향으로 미끄러진다. 죠 본체는 두고 접촉면만
    갈아 끼우는 교체형 인서트를 만든다.
    - 죠 실측 기준: 파지 평면 x=-49.4, Y -84.2~-11.7(72.5), Z -29.3~28.2(57.5)
    - V홈은 공짜가 아니다. 인서트가 두꺼워지면 유효 개폐가 줄어 병이 안 들어간다.
    90도 V는 유효 개폐 69mm에 커버 지름 D42라 병을 못 잡는다. 기본값을
    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
    [insert_A_flat_pad.step, insert_A_flat_pad.stl, insert_B_v_groove.step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]
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2026-09-03 feat(description): Robonine 팔 체인을 걷어내고 SO-101 체인 + ggao50 그리퍼로 교체
    평행그리퍼 형상만 가져오려던 것이 팔 체인 규약까지 바꿔 놓은 상태였다.
    Robonine 그리퍼를 안 쓰기로 했으므로 팔 체인도 검증된 SO-101 로 되돌린다.
    - third_party/robonine, meshes/robonine, generate_parallel_arm_xacro.py 제거
    - third_party/so_arm_101 신설. 상류 TheRobotStudio SO-ARM100/101(Apache-2.0)
    형상에 로컬 JD-AMR 실기에서 검증된 오리진·한계를 쓴다. NOTICE 로 출처 명시
    - 관절 이름을 shoulder_pan/shoulder_lift/elbow_flex/wrist_flex/wrist_roll 로
    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
    [base_link.stl, base_motor_holder_so101_v1.stl, base_so101_v2.stl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]
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2026-09-03 fix(gripper): 인서트를 죠 테이퍼에 맞는 사다리꼴로 재설계
    첫 인서트는 파지면이 60x50 mm 연속 평면이라는 전제였는데 그 면이 없다.
    파지면은 손끝으로 갈수록 좁아지는 테이퍼다 (높이 = 0.682 x Y + 67.5).
    50 mm 를 받을 수 있는 구간이 폭 1 mm 뿐이었다.
    - 부착 창을 높이 40 mm 이상인 뿌리 쪽 Y -42 ~ -14 (28 mm) 로 한정
    - 외곽을 죠 테이퍼를 따르는 사다리꼴로 (높이 34.0 -> 52.3 mm, 2 mm 인셋)
    - 볼트를 손가락 방향으로 이동. 홈이 Z 로 파여 Z=0 에만 재료가 남는다
    - 홈 폭 기본값 30 -> 24 mm. 부착 창 28 mm 가 상한이다
    - source_container 지름 상한 72 ->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
    [insert_A_flat_pad.step, insert_A_flat_pad.stl, insert_B_v_groove.step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]
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2026-09-03 chore(design): 현행 설계에서 Robonine 흔적을 전부 제거
    그리퍼를 ggao50 으로 확정했는데 Robonine 이 대안·비교 기준으로 남아 있었다.
    안 쓰는 것을 규격과 계산에 남겨 두면 어느 쪽이 현행인지 헷갈린다.
    - YAML: alternative_reference 블록, calculated_robonine_* 값, 토크 비교 행, 링크
    - calculate_250mm_design.py: ROBONINE_GRIPPER_MASS_KG, replace_gripper_mass(),
    비교 계산 블록과 관련 assert 제거
    - 문서 8종을 ggao50 기준으로 갱신. 이전 체인이 섞여 있었다는 서술은
    2026-09-03 개정으로 해소됐다는 서술로 교체
    - mechanical_calibration.yaml 의 관성 출처를 바로잡음.
    s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
    [mechanical_calibration.yaml]
2026-09-03 fix(repo): 사용자 렌더 이미지를 추적에서 제외
    직전 커밋에서 git add -A 로 디렉터리를 통째 스테이징하다 미추적이던
    docs/renders/ 10개(16 MB)가 함께 올라갔다. 사용자 개인 작업 파일이라
    추적에서 빼고 .gitignore 에 docs/renders/ 와 .omx/ 를 넣어 재발을 막는다.
    파일은 작업 디렉터리에 그대로 남는다.
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2026-09-10 feat(sim): 300mm 양팔 로봇 URDF와 Isaac 모델 추가
    [arm_adapter.step, arm_adapter.stl, astra_cradle.step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]
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2026-09-10 docs(servo): Phase 반전 사고 분석과 원본 데이터, 발산 감지 추가
    그리퍼 서보 ID 6 의 Phase 가 개체에 맞지 않는 12 로 써져 있어 위치 루프가
    양의 되먹임이 됐고, 어떤 목표든 열림 끝으로 달아나 레일 이탈이 4회 났다.
    가설 8개를 데이터로 기각한 과정, 결정적 EEPROM 대조, 해결(Phase 76 + 재부팅),
    교훈, 포트폴리오용 요약을 사고 분석 문서에 남긴다.
    원본 데이터를 assets 에 둔다: 실물 테스트 로그(터미널 출력 그대로), 수정 후
    두 보드 12개 서보 EEPROM 전체 덤프, 오프셋·한계 변경 이력.
    servo_goto.py 에 발산 감지를 넣는다 — 목표에서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
    [servo_goto.py, servo_offset.py]
2026-09-10 fix(servo): 그리퍼 캘리브레이션 최종값과 EEPROM 재부팅 규칙 반영
    검증 완료값으로 갱신한다 — 닫힘 3500, 열림 506, 한계 546~3480, 오프셋 693,
    Phase 76, 30.5 카운트/mm(2890 → 자로 2 cm, 1670 → 6 cm 확인).
    EEPROM 을 켜진 채로 쓰면 재부팅 전까지 제어가 꼬이는 것을 실측으로 확인해
    절차와 사고 분석에 "EEPROM 쓴 뒤 재부팅" 규칙을 넣는다. servo_goto.py 의
    도달 판정을 ±10 으로 넓힌다 — P게인 16 서보가 5~8 카운트 앞에서 서는 것을
    정지로 오판하던 문제.
    Claude-Session: https://claude.ai/code/session_019AkefRzDe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
    [servo_goto.py]
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2026-09-10 fix(servo): goto 가 시험용 속도·가속을 서보에 남기지 않도록 원복
    --speed 값을 SRAM Goal_Speed 에 쓰고 그대로 끝내서, 그 뒤 텔레옵이 그 속도로
    기어갔다(100 카운트/s = 전 행정 29 초). 시작 때 읽어 두고 끝·중단 어느 경로든
    되돌린다. 모의로 확인.
    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
    [servo_goto.py]
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2026-09-11 fix(calibration): 오른팔 리더·팔로워 재캘리브레이션 (EEPROM-JSON 불일치 수정)
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2026-09-30 feat(ik): 상대 IK와 엔코더 보정으로 컵 상승 시험 연결 (#58)
    * feat(ik): 현행 보정으로 고정 좌표 컵 접근 준비
    * feat(ik): 감독형 컵 픽앤플레이스 실행 전 준비와 접촉 검증 추가
    * feat(dashboard): RGB 세 대 관제와 양팔 토크 해제 버튼 추가
    * feat(servo): 현재 위치 기준 손목 단일축 시험과 정지 감시 추가
    * feat(calibration): EEPROM 미변경 범위 후보 기록과 검증 추가
    * feat(calibration): 양팔 실측 범위 적용과 실패 복구 도구 추가
    * feat(servo): 보정 기반 그리퍼 부분 개폐와 최종 토크 해제 검증 추가
    * fix(ik): 컵 실측 배치 기록과 실행 중 정지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
    [bench_relative_ik.py, camera_dashboard.py, compare_joint_conventions.py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]
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2026-10-02 fix(calibration): 새 양팔 보정 반영과 최신 main 충돌 해결 (#54)
    * docs(gripper): 그리퍼 STL(A/B) 재질 5케이스 비교판정 문서 추가
    * feat(teleop): 왼팔 캘리브레이션 확보, 양팔 bi_so_follower 구성 추가
    좌우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
2026-10-14 fix(rollout): 카메라 타임아웃이 토크 급정지로 이어지는 문제 패치 보존 (#64)
    * docs(teleop): 로컬 카메라 인덱스 매핑 문서와 확인 스크립트 추가
    손목캠 2대·탑뷰 1대 구성에서 카메라 인덱스를 구분하기 위한 참고 문서와
    index 확인용 스크립트를 옛 작업 폴더에서 이 git 폴더로 옮긴다.
    * feat(teleop): Astra S 뎁스카메라 RGB 브리지와 좌우반전·노출 고정 반영
    Orbbec Astra S를 3인칭 카메라로 쓰기 위해 OpenNI2 컬러 스트림을 OBS 가상
    카메라로 중계하는 브리지와 라이브 미리보기 도구를 추가한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
2026-10-14 fix(camera): 렌즈 높이를 상판 위 54cm로 갱신 (#65)
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2026-10-15 docs(il): SmolVLA 실물 롤아웃 떨림 디버깅 세션 인계 기록 추가 (#69)
    * docs(il): SmolVLA 실물 롤아웃 떨림 디버깅 세션 인계 기록 추가
    끊김 원인(청크 재계산), RTC 배제 근거, max_relative_target 5/10/20도
    실험 결과를 정리하고 다음 세션이 이어갈 떨림 원인 진단 절차를 남긴다.
    재사용 가능한 비상 토크 OFF 스크립트도 함께 추가.
    * fix(docs): CI 링크 검사 대응 - 미커밋 문서 참조를 링크에서 제외
    20261009 SSOT 가이드는 아직 저장소에 없어 로컬 링크 검사가 실패했다.
    클릭 링크 대신 평문 경로 표기로 바꿔 범위 밖 파일을 끌어들이지 않는다.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
2026-10-15 docs(il): SmolVLA 떨림 원인 확정 — 카메라 인덱스·미러 오정렬, max_relative_target=20 채택 (#72)
    손목캠 좌/우 인덱스 뒤바뀜과 top 카메라 mirror 누락이 실제 원인이었다.
    수정 후 max_relative_target 재스윕으로 20도를 기본값으로 정했다. 남은
    가다서다 끊김은 청크 재계산 지연 추정이며 RTC 재검증이 다음 단계다.
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2026-10-20 fix(navigation): 도크 접근과 이동 경계의 지연 및 입력 회복 개선 (#75)
    * fix(navigation): 출발 지연 경로와 주차 실행 결과 판정 수정
    * fix(navigation): 근접 재주차 회전과 마지막 면 정렬 수정
    * docs(navigation): 재주차 회전 오류와 수정본 주행 결과 기록
    * fix(navigation): 실측 기준 책상 면 보정과 최종 접근 속도 조정
    * docs(navigation): 책상 면 보정과 양측 12mm 실측 기록
    * fix(navigation): 급수대 경유와 연속 정밀접근 및 테이블 점유 후보 반영
    * docs(navigation): 연속 접근 수정본의 파이 반영 근거 기록
    * fix(navigation): 평행한 3센치 도크 배치와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
2026-10-20 fix(navigation): 출발 시간 예산과 도크 초기화 오류 수정 (#76)
    * fix(navigation): 평행한 3센치 도크 배치와 테이블 킵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
2026-10-20 fix(navigation): 정지 중 지도 갱신의 정밀주차 오판 수정 (#77)
    * fix(navigation): 정지 중 지도 갱신의 정밀주차 오판 수정
    * docs(navigation): 실제 근접 0cm 보고와 내부 거리 불일치 기록
    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
2026-10-20 fix(navigation): 후면 도킹 TF와 킵아웃 충돌 및 조기 감속 수정 (#78)
2026-10-21 fix(navigation): 근접 비틀림의 추가 전진을 수정하고 조향값 복원 (#81)
2026-10-21 docs(il): 핸드오프 데이터 수집 인프라 트러블슈팅 기록·도구 추가 (#80)
    * docs(il): 핸드오프 데이터 수집 인프라 트러블슈팅 기록·도구 추가
    물따르기→컵배치 통합 녹화 스크립트(재연결 실패 지점 제거, 명령어 1회=1라운드),
    카메라 인덱스 DevicePath 리졸버, LeRobot 이미지 저장 무음 실패 버그 수정 패치,
    그리고 이미 수집된 9+9개와 앞으로 모을 데이터의 무결성 검증(스키마·타임스탬프·
    관절 연속성·카메라 FPS/싱크)을 docs/experiments 3개 문서와 PROGRESS에 기록했다.
    * feat(il): 핸드오프 녹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
2026-10-22 feat(navigation): 뎁스 점군 분리와 책상 추적 관측 연결 (#83)
    * fix(navigation): 근접 비틀림의 추가 전진을 수정하고 조향값 복원
    * docs(navigation): 주행 변경은 브랜치 로컬 커밋을 기본으로 유지
    * fix(amr): 후면 도킹 각도와 근접 기억점 판정을 보정
    * docs(amr): 출발 실패 시 배터리 우선 확인 규칙 기록
    * fix(amr): 출발 실패의 실제 배터리와 센서 사유 보존
    * docs(git): 목적별 브랜치와 피알 완료 후 정리 규칙 명시
    * fix(amr): 제어기 응답 확인과 출발 전 세션 복구 수정
    * fix(amr): 도크 킵아웃 제거와 후면 면 기준 접근 적용
    * fix(navigation):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
2026-10-26 feat(amr): 새 지도의 급수대 등록 주차와 도크 복귀 연결 (#84)
    * fix(navigation)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
2026-10-27 docs(amr): 강의실 지도와 주차 좌표 인계 (#85)
    * fix(amr): 참조 평면 계산 자세의 상태 표기 정정
    * fix(amr): 급수대 연속 접근과 후면 도킹 정렬 개선
    * fix(amr): 운영자 호출과 추가 알림 경로 제거
    * fix(amr): 급수대 표시 선택 누락 수정과 테이블1 교시 기록
    * fix(amr): 수동 조종 응답 대기 해소와 테이블 관측 지도 갱신
    * fix(amr): 저장된 테이블 위치를 알비즈에 표시
    * feat(amr): 급수대와 테이블 연속 주차 경로 연결
    * fix(amr): 급수대 좌우 정렬 비수렴과 도크 출발 경로 수정
    * fix(amr): 도크 정합 원본 기준 유지
    * docs(amr): 강의실 지도와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
2026-10-29 feat(il): 핸드오프 롤아웃 래퍼 추가 — 그리퍼 과부하 예방·끝 자세 선택·작업 끝 자동 감지·붓기 훅 (#82)
    관절 연속성·카메라 FPS/싱크)을 docs/experiments 3개 문서와 PROGRESS에 기록했다.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
2026-10-29 fix(il): 실차 연결 크래시 수정·Astra 정렬 깊이 Pi 송신(AST1) (#89)
    * fix(il): 상주 실행기 기동 시 pyarrow access violation 크래시 수정
    카메라 번호 찾기(Windows COM) 뒤에 lerobot을 import하면 pyarrow.dataset에서
    access violation으로 꺼졌다(start_scenario.bat의 manip-service 창이 바로 닫힘, 3회 재현).
    lerobot.motors·lerobot.rollout을 먼저 import한다. 실차 준비 완료 3회 정상.
    * fix(il): 오른쪽 손목캠 USB 경로 갱신(b7049f8 -> 1b3f2dc8)
    * feat(depth): Astra RGB·정렬 깊이를 Pi 정밀주차로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
2026-10-30 fix(il): 카메라 끊김 보호·오른팔 복구 접기·새 노트북 작업 인계 (#90)
    * fix(il): 카메라 끊김에도 팔 접기·정책 실행이 멈추지 않게 보호
    2026-10-30 실차 통합에서 손목캠 USB가 빠지자 물따르기 뒤 오른팔 접기와 컵배치가
    관측 실패로 중단됐다.
    - 팔 접기·자세 확인은 read_joints로 모터 위치만 읽는다(카메라 무관)
    - camera_fallback: 프레임이 끊기면 마지막 프레임으로 계속, 2초마다 다시 연결(번호가
    바뀌면 물리 경로로 재탐색), 다시 연결 중에도 로봇을 연결된 것으로 본다
    - stow_right 복구 명령(오른팔만 접어 carrying_cup)
    - 연결이 끊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
2026-10-30 fix(amr): Windows 조작 연동과 연속 정밀주차 통합 (#86)
    * docs(amr): 강의실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
2026-10-30 fix(amr): 컵·병 정렬과 출발 복구 개선 (#91)
    * test(amr): 주문부터 도크 복귀까지 비이동 통합 모의 추가
    * fix(amr): 출발 복구와 영상 재획득 지연 수정
    * fix(amr): 컵과 병의 유효 후보쌍 선택 개선
    * docs(amr): 도크 초기화와 출발 준비 결과 기록
    * docs(amr): 실차 실패 근거와 사전 로딩 운영 반영
2026-10-30 chore(il): OMEN 노트북 팔 포트·손목캠 힌트·환경 점검 스크립트 반영 (#92)
    * fix(il): Windows 배치 파일을 CRLF로 체크아웃
    core.autocrlf=false 클론(새 노트북 인계 문서의 받기 방식)에서는 .bat이 LF로 받아진다.
    cmd가 LF만 있는 배치 파일을 잘못 읽어 set 값이 비고 주석 조각이 명령으로 실행돼
    start_scenario.bat의 조작 실행기 창이 바로 닫혔다(echo 시험: LF 깨짐, CRLF 정상).
    *.bat, *.cmd에 text eol=crlf를 지정한다. 저장된 blob은 이미 LF라 내용 변경은 없다.
    Claude-Session: https://claude.ai/code/session_01W67JaTLrZ6Mng67wV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
2026-10-30 fix(amr): 테이프 정렬·깊이 지연 개선과 시나리오 실행 안내 (#94)
    * feat(navigation): 급수대 전면 테이프 정렬 후보와 재접근 입력 연결
    * fix(navigation): 테이프 접근 목표 고정과 검출 처리 단축
    * fix(navigation): 깊이 계산 지연의 단절 오판과 반복 연산 개선
    * docs(navigation): 테이프 재주차 반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
